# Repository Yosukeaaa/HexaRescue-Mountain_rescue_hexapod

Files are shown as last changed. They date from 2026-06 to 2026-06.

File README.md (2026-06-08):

HexaRescue is a mountain‑rescue hexapod robot designed to navigate rough terrain, detect potential victims, and transmit reliable information to rescue teams.
The robot combines robust mechanical design, modular electronics, and onboard AI to operate in challenging environments.



## Mechanical Design
HexaRescue is a 50 cm hexapod with six legs, each offering three degrees of freedom for stability and obstacle‑crossing.



The robot is built on three stacked layers:

  - Top layer — Jetson Nano + ESP32

  - Middle layer — 2S Li‑Po battery (centered for stability)

  - Bottom layer — SSC‑32U servo controller + power converters

Most parts are 3D‑printed in PETG, while the chassis is metal for rigidity.
The feet use TPE pads for improved grip on uneven terrain.

## Electrical Architecture
Power comes from a 2S Li‑Po battery, split into three rails:

  - Direct Li‑Po → SSC‑32U powering 20 servos
  - 5 V buck converter → Jetson Nano + ESP32
  - 3.3 V buck converter → sensors

## Sensor Placement
Sensors are positioned to maximize reliability:

  - GPS at the front, away from EMI sources
  - RGB + thermal cameras on a 2‑DOF camera arm
  - Distance sensor at the bottom for ground‑level obstacle detection

## Software Architecture & AI
The system uses a simple but effective communication scheme:

The ESP32 hosts a Wi‑Fi network and serves a web interface
The smartphone connects simultaneously to:

  - ESP32 → commands + telemetry
  - Jetson Nano → video stream



The Jetson Nano runs YOLOv5 to detect people.

When a detection occurs, the ESP32 cross‑checks it with thermal data from the GridEYE sensor. 

 

If both confirm a human presence, the operator receives an alert popup with timestamp and GPS coordinates.

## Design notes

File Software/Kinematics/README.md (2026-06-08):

## Inverse Kinematics
The inverse kinematics is a crucial part of any hexapod robot, as it determines how each leg should move to achieve a desired body position or trajectory.
For HexaRescue, the kinematic equations were developed at the beginning of the project using the 3D models of the robot to accurately define joint geometry and movement constraints.

These calculations were then validated in real conditions through the test scripts available in this folder.
They serve as the mathematical foundation for the robot’s locomotion, ensuring stable, precise and predictable movements across uneven terrain.



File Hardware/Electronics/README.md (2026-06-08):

HexaRescue is powered by a 2S Li‑Po battery. From this battery, three separate power rails are derived:

    - Servo power rail — The SSC‑32U board is connected directly to the Li‑Po and supplies power to the 20 servomotors 
    (18 for the legs, 2 for the camera arm).

    - 5V rail — A 5V buck converter steps down the battery voltage to power the Jetson Nano and the ESP32.

    - 3.3V rail — A 3.3V buck converter provides a stable voltage for all sensors.

A main power switch is placed right after the battery to ensure safety during startup and maintenance.

The following diagram shows the overall electrical architecture of the robot.



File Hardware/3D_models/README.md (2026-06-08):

This folder contains the 3D model files for HexaRescue.

HexaRescue

https://github.com/user-attachments/assets/52c7025c-e5b4-4ebd-b071-2c9e1bfe73b1

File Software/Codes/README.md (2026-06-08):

This folder contains all HexaRescue source code, except the Jetson Nano and the AI code.

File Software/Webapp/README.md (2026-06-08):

# Web Application Overview
The HexaRescue web application is divided into four main sections, each designed to give the operator a clear and efficient control interface.

  ## Status & Telemetry Panel
  This section displays the robot’s real‑time state through colored indicators.
  Each LED‑style indicator reflects the health of a subsystem (robot status, sensors, communication, ...).
  The panel also shows the robot’s live position by GPS coordinates.

  ## Multi‑View Camera Interface
  The operator can switch between three different video feeds:
  - RGB view — standard camera feed  
  - Thermal view — temperature‑based visualization  
  - Fusion view — combined RGB + thermal overlay for enhanced detection

 -->  --> 

  This setup provides a complete understanding of the environment, even in low‑visibility conditions.

  ## Robot Control Panel
  This section provides direct control over the robot’s movements:
  - Forward / backward  
  - Rotation  
  - Head movement (left/right and up/down)  

 In addition to directional controls, the interface includes sliders that allow the operator to adjust
  the robot’s walking height, body elevation, and overall movement speed, offering precise control
  over its locomotion.
  
  Commands are sent instantly through the ESP32, ensuring responsive control during navigation.

  ## Detection Alerts & History
  All confirmed detections appear in a dedicated alert feed.
  Each entry includes:
  - Detection time  
  - GPS coordinates  
  - Thermal signature  

  This creates a detailed history of all potential victims detected during the mission.

  ## Entire web application :


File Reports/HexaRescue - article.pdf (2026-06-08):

Abstract — This article presents the early development of HexaRescue, a hexapod [1] mountain rescue robot. The project focuses on creating a 3-DOF [2] leg architecture actuated by servomotors. Each prototype was individually tested. At this stage, three legs have been assembled and were set in motion. These early results confirm the feasibility of this hexapod but also the reliability of the chosen design.

Index terms — Hexapod, legged robot, Arduino, servomotor, inverse kinematics

I. INTRODUCTION

Hexapod robots offer advantages compared to wheeled robots. They can handle obstacles better and have greater stability on uneven terrain. HexaRescue is based on this idea. It is a 6-legged robot designed to assist rescue teams and reduce intervention time. Each leg has 3 degree of freedom (DOF). They are controlled by an SSC-32 board [3] and Arduino UNO [4]. The main structure is in metal, and the legs are 3D-printed in Polyethylene Terephthalate Glycol (PETG). The main goals of HexaRescue are to move on irregular terrain, detect victims using a thermal camera, and transmit their GPS position to rescue teams.

This article is organized as follows. Section II presents the mechanical design of the robot. Section III describes the electronic architecture and the components used. Section IV introduces the control code and the first locomotion tests. Finally, Section V presents the conclusions.

II. MECHANICAL DESIGN

The first version of the robot was made entirely in metal. It was a kit with servomotors and metal legs. However, this first version had several limitations. Firstly, the legs were too short so the robot would have difficulties straddling branches or rocks. Secondly, the build quality was insufficient. So, it was decided to keep only the metal body and 3D print the legs. This compromise gives HexaRescue good structural strength but also a strong and durable base for mounting the new legs.
The new legs were entirely designed using Computer-Aided Design (CAD) (Fig.1) with fusion360 [5]. Multiple versions were needed to obtain a leg that was rigid, practical, and aesthetically clean. Then, these legs were manufactured using a 3D printer and Computer-Aided Manufacturing (CAM). PETG is the filament used because it has good mechanical properties: lightweight, mechanical strength, and good shock resistance. Moreover, using CAD/CAM [6] and 3D printed legs is good for adjusting the model and allows modular parts that can easily be replaced.

*E-mail : pierre.masseglia@etu.unice.fr

Finally, a 3 DOF leg architecture was chosen for the legs because, compared to a 2 DOF leg architecture, it offers a wider range of motion. Thanks to a 3 DOF leg architecture, a leg can step over an obstacle by lifting its hip and rotating the leg. Some motions would not be possible without the 3rd DOF.

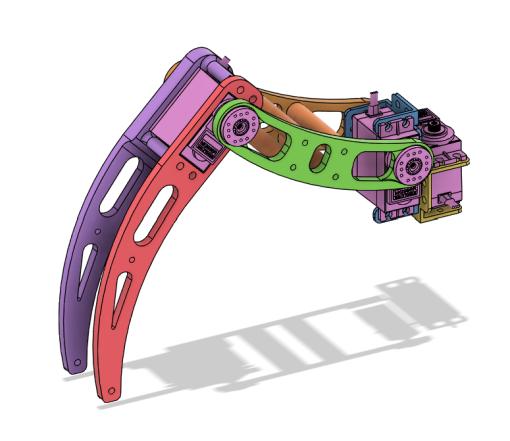
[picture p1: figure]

Figure 1 : CAD model of a single 3-DOF leg created in Fusion 360.

III. ELECTRONIC ARCHITECTURE

The electronic architecture of HexaRescue is composed of boards and sensors, as illustrated in Fig. 2.

A. Main electronics
The electronic architecture of HexaRescue is based on an Arduino UNO combined with an SSC-32 board, used because it can pilot several servomotors at the same time. This board is precise and reliable. The legs use servomotors TD-8135MG [7] with a force of 35 kg.cm. It offers high torque which is necessary to hold the weight of the robot, to facilitate motions, but also to carry some light tools. HexaRescue is now powered by a laboratory power supply, so it currently operates exclusively via wired power.
B. Sensors
The robot also integrates several sensors designed to improve its perception of the environment. A HC SR-04 [8], an ultrasonic sensor, is placed at the front of the body to detect obstacles and avoid front collisions. A thermal camera AMG8833 [9] is also fixed at the front of the robot. It can distinguish heat sources and is a key element for detecting victims in mountain environments. This combination of sensors provides an initial perception layer, which will be expanded as the prototype continues to develop.

## HexaRescue – Hexapod mountain rescue robot

Masseglia Pierre

University of Côte d'Azur, Polytech ‘Lab UPR UniCca 7498, Sophia Antipolis, France

Finally, HexaRescue uses an HC-05 [10] Bluetooth module to be controlled by an application on a smartphone.

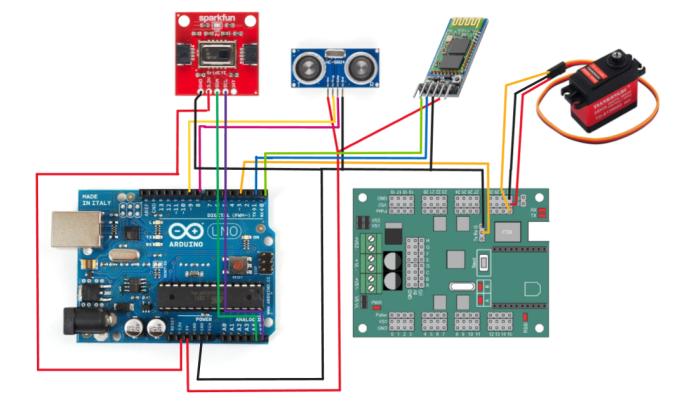
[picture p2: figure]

Figure 2 : Electronic achitecture of HexaRescue.

IV. LOCOMOTION AND CODE

A. Inverse kinematics and control of the legs
The locomotion of HexaRescue is based on the calculations of inverse kinematics equations [11]. This method allows converting a target position in space (x, y, z) into the corresponding angles for each servomotor (θ1, θ2, θ3), where θ₁, θ₂, and θ₃ represent the hip yaw, hip pitch, and knee pitch angles respectively.
These calculations are the basis of every leg movement and that ensures that each foot follows the good trajectory with precision.
B. Locomotion modes and tripod gait
HexaRescue integrates different operational modes for the moment.
- Shut down mode: the robot is inactive. All the legs are pointing toward the sky, and the body is resting on the ground, as presented in fig.3.
- Enable mode: the legs move from their shut down position to the neutral position, and they slowly lift the robot into a stable posture, as presented in fig.4.
- Neutral position mode: each leg is in a stable position without any movement.
- Forward mode: the robot walks using a tripod gait, a gait in which three legs are moving while the others are stabilizing the robot, as shown in Table I.

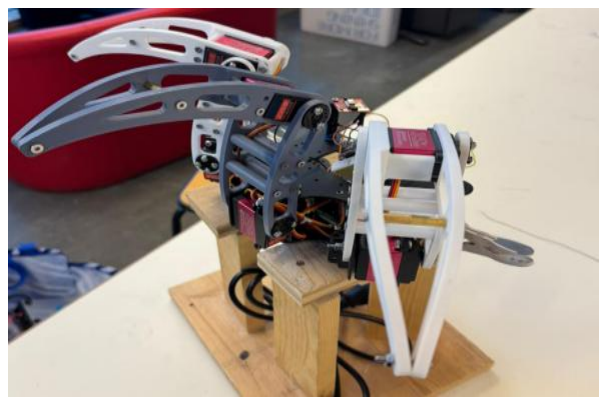
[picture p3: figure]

Figure 3 : Shut down mode.

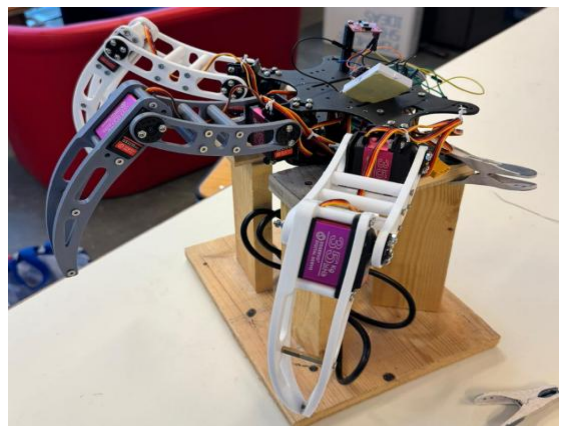
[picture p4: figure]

Figure 4 : Enable mode.

TABLE I. Table representing the tripod gait, with black cells indicating when the legs are in contact with the ground.

LEG 1

LEG 2

LEG 3

LEG 4

LEG 5

LEG 6

The height of the robot can also be adjusted dynamically. This allows the body of the robot to be raised or lowered depending on the user’s need or the terrain.

C. Code structure
All the elements described above were integrated into the main program of HexaRescue. To improve accessibility and maintenance, the code was placed into different classes and files.
Each class has a precise role: one manages the legs, another handles the inverse kinematics calculations, and another communicates with the SSC-32 board to send all the data at the same time to the servomotors.
This organization helps keep the code readable and structured, and makes it easier to improve, such as new functions or sensors. All this code was written in the Arduino IDE [12].
V. CONCLUSION
HexaRescue is a hexapod robot designed to move in a stable way thanks to the inverse kinematics equations and the tripod gait which is simple but effective. At this stage, three legs have been assembled and tested but all the different functioning modes were correctly integrated and tested, as well as the sensors. The structure of the code is helpful to maintain the robot and to add new gaits or sensors.

It can be a lot more evolutive than before. This works is a solid base for HexaRescue, and to add new functionalities. REFERENCES

[1] S. Hirose and Y. Umetani, “Kinematic control of a six -legged walking
vehicle,” Proceedings of the 5th International Symposium on Industrial Robots, pp. 245
–254, 1976.
[2] J.
-L. Lagrange, Mécanique Analytique. Paris, France: Desaint, 1788.
[3] Lynxmotion, SSC-32 Servo Controller User Guide, Lynxmotion/RobotShop, 2005
[4] Arduino, Arduino UNO Rev3 Datasheet, Arduino AG, 2015.
[5] Autodesk, Fusion 360 Official Documentation, Autodesk Inc., 2013.
[6] D. T. Ross, “Computer
-Aided Design: A Statement of Objectives,” Proceedings of the Eastern Joint Computer Conference, pp. 313 –319,
1960.
[7] Wishiot, TD
-8135MG High

-Torque Servo Motor Specifications, Wishiot, 2020.
[8] SparkFun Electronics, HC-SR04 Ultrasonic Distance Sensor Datasheet, SparkFun, 2014.
[9] Panasonic Corporation, AMG8833 Infrared Array Sensor “Grid -EYE”
Datasheet, Panasonic, 2016.
[10]
Y

-MCU, HC-05 Bluetooth Module Datasheet, JY

-MCU / Huayuxing
Electronics, 2010.
[11] D. L. Pieper, “The kinematics of manipulators under computer control,” Ph.D. dissertation, Dept. Mech. Eng., MIT, Cambridge, MA, 1969.
[12] Arduino, Arduino IDE
– Integrated Development Environment Documentation, Arduino AG, 2015.

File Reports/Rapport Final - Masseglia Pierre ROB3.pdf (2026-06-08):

### Robotique, Systèmes autonomes

# Projet de robotique – Rapport Final

## Année scolaire 2025-2026

## HexaRescue – Hexapode de secours en montagne

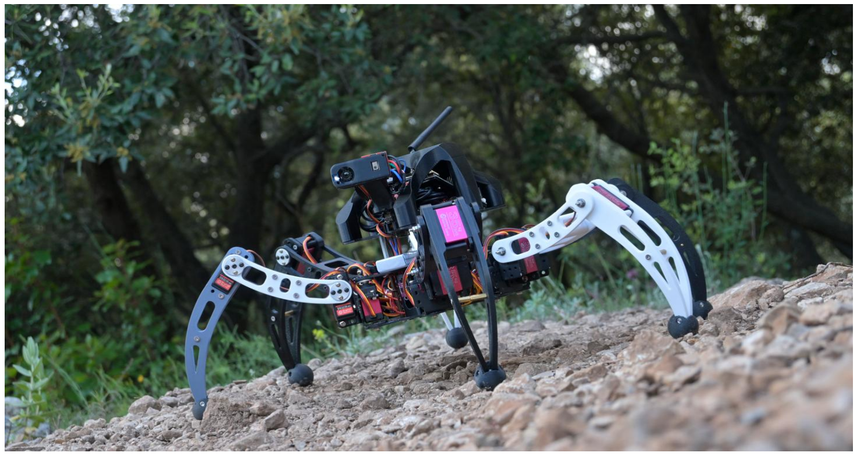
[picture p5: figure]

# Etudiant : Masseglia Pierre

Ecole Polytechnique Universitaire de Nice Sophia-Antipolis, formation robotique (systèmes autonomes) 930 route des Colles, 06410 BIOT

SOMMAIRE

I.1. Caractéristiques mécaniques

I.2. Matériaux utilisés

II.1. Schéma électrique

II.2. Implantation des capteurs

III.1. Système de contrôle du robot

III.2. Intelligence artificielle

IV.1. Coût du projet

IV.2. Difficultés rencontrées

IV.3. Améliorations possibles du rapport bibliographique

# Introduction

Chaque année en France, plusieurs centaines d’interventions sont réalisées en montagne pour porter secours à des victimes, parfois dans des zones difficiles d’accès. Ces conditions rallongent les délais d’intervention et peuvent réduire les chances de survie. Un outil capable d’explorer rapidement un terrain accidenté et de transmettre des informations fiables constitue donc une aide précieuse pour les équipes de secours.

Le robot HexaRescue répond à cet objectif. Il s’agit d’un hexapode d’environ 50 cm, capable d’évoluer sur des terrains complexes grâce à ses six pattes. Équipé de capteurs, il peut détecter et éviter les obstacles, repérer la présence potentielle de victimes et transmettre leur position GPS.

Le présent rapport expose l’ensemble des démarches de conception du prototype.

# Chapitre I : Conception mécanique

I.1. Caractéristiques mécaniques

HexaRescue est un robot hexapode conçu pour évoluer dans des environnements montagneux difficiles d’accès. Sa structure mécanique repose sur une architecture à six pattes, chacune dotée de trois degrés de liberté, offrant une excellente stabilité et une capacité de franchissement élevée. Cette configuration permet au robot de progresser sur des terrains irréguliers, de franchir des obstacles et de maintenir une posture stable même en conditions dégradées.

La structure générale du robot est organisée en trois étages distincts, chacun dédié à un sous-système spécifique :

- L’étage supérieur accueille l’électronique principale, notamment la Jetson Nano et l’ESP32. Cette position facilite l’accès, la maintenance et limite l’exposition aux chocs.
- L’étage intermédiaire intègre la batterie LiPo 2S. Placée au centre du robot, elle abaisse le centre de gravité et améliore la stabilité lors de la marche.
- L’étage inférieur supporte la carte SSC32U et les différents convertisseurs d’alimentation. Cette disposition réduit l’encombrement des câbles et simplifie le câblage des servomoteurs.

Le robot embarque également un bras caméra orientable à deux degrés de liberté (yaw et tilt), permettant de diriger précisément les caméras vers une zone d’intérêt.

I.2. Matériaux utilisés

Le choix des matériaux a été guidé par la nécessité d’obtenir un robot robuste, léger et résistant aux contraintes mécaniques rencontrées en montagne.

- Le châssis est réalisé en métal afin d’assurer une rigidité élevée et de limiter les déformations lors des déplacements ou des chocs.
- Tous les autres éléments ont été imprimés en 3D en PETG avec plusieurs périmètres et un remplissage de type gyroid. Ce choix offre un compromis optimal entre résistance, flexibilité et temps d’impression.
- Les extrémités des pattes possèdent des boudins en TPE, plus souples que le TPU classique, qui améliorent l’adhérence au sol et absorbent mieux les irrégularités du terrain.

# Chapitre II : Conception électrique

II.1. Schéma électrique

L’alimentation du robot repose sur une batterie LiPo 2S. À partir de cette batterie, trois étages d’alimentation distinctes sont dérivés :

- La carte SSC32U [1] est alimentée directement en sortie de la LiPo. Cette carte alimente les 20 servomoteurs du robot (18 pour les pattes, 2 pour le bras caméra).
- Un buck 5V convertit la tension de la batterie vers 5 V, tension utilisée pour alimenter la Jetson Nano et l’ESP32 [2].
- Un buck 3,3V est lui dédié aux capteurs afin d’assurer une alimentation stable et suffisante à l’ensemble des capteurs.

Un interrupteur général est placé juste après la batterie pour garantir la sécurité lors de l’allumage et de la maintenance.

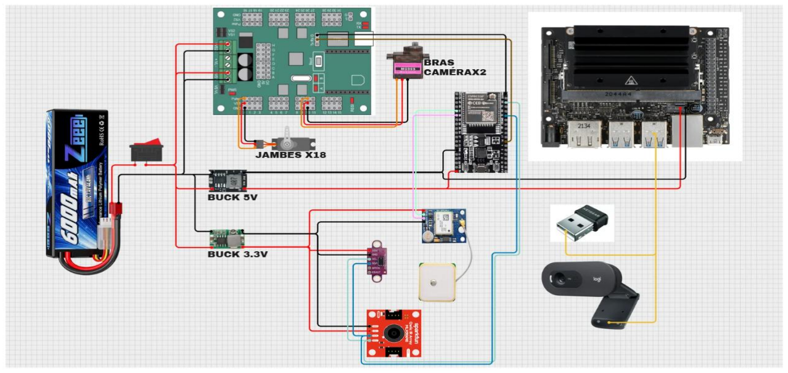
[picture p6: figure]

Figure II.1. Schéma électrique d’HexaRescue

II.2. Implantation des capteurs

Les capteurs ont été positionnés de manière stratégique pour optimiser la qualité des mesures et réduire les interférences :

- Le capteur GPS est placé à l’avant du robot, éloigné de la Jetson Nano et de l’ESP32 pour limiter les perturbations électromagnétiques et fiabiliser les données reçues.
- Les caméras (RGB et thermique) sont montées sur le bras orientable, permettant de balayer la scène et de cibler précisément une zone d’intérêt.
- Le capteur de distance est situé à l’étage le plus bas du châssis pour détecter les obstacles proches du sol.

Cette disposition assure une acquisition de données fiable et cohérente avec les besoins du robot.

# Chapitre III : Architecture logicielle et intelligence embarquée

III.1. Système de contrôle du robot

Le fonctionnement logiciel repose sur une communication simple entre l’ESP32, la Jetson Nano et un smartphone.

L’ESP32 génère son propre réseau Wifi auquel l’opérateur se connecte depuis son smartphone. En entrant l’adresse IP de l’ESP32 dans un navigateur, l’utilisateur accède à une application web embarquée, stockée dans l’ESP32.

Une fois la webapp chargée, le smartphone établit deux connexions simultanées :

- Une vers l’ESP32 pour les commandes et la télémétrie.
- Une vers la Jetson Nano pour le flux vidéo.

III.2. Intelligence Artificielle

La Jetson Nano exécute un modèle de détection basé sur YOLOv5 [3], entraîné pour identifier des personnes dans l’environnement. Lorsqu’une détection est réalisée, la Jetson envoie une alerte à l’ESP32 via le module WebSocket.

L’ESP32 croise alors cette information avec les données de la caméra thermique GridEYE. Si les deux capteurs confirment la présence d’une personne, un popup d’alerte apparaît dans la webapp, contenant l’heure de détection ainsi que les coordonnées GPS de la victime. Cette fusion de capteurs permet de réduire les faux positifs et d’améliorer la fiabilité du système.

Voici l’algorithme de fonctionnement de la détection d’une victime.

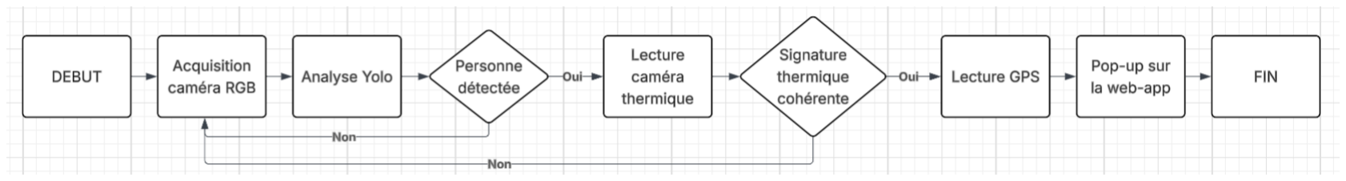
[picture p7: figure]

Figure III.1. Algorithme de détection et confirmation multi-capteurs

# Chapitre IV : Analyse des coûts et retour d’expérience

IV.1. Coût du projet

Le coût total du projet HexaRescue peut être estimé en prenant en compte le matériel utilisé ainsi que le temps de travail nécessaire à la conception.

Concernant le coût matériel, en comptant les différentes cartes électroniques, les servomoteurs, et tous les capteurs utilisés, nous en avons pour environ 600€.

Concernant le coût ingénieur, nous avons passé environ 24*4h = 96h en cours de robotique expérimentale. Personnellement, je pense avoir travaillé 30*5h = 150h en plus, soit un total de 246h.

Au taux horaire, cela représente un total de 246 * 23,75€ = 5 842,5€

Ainsi, au total, HexaRescue aura coûté 6 442,5€.

IV.2. Difficultés rencontrées

La réalisation du robot a été marquée par plusieurs difficultés techniques importantes.

La première série de problèmes est apparue lors des premiers tests de marche. La carte SSC-32U, utilisée pour piloter les servomoteurs, causait parfois des comportements inattendus et imprévisibles. Les pattes du robot entraient donc régulièrement en collision, ce qui nécessitait de recalibrer entièrement les pattes à chaque essai. Cette phase a été particulièrement chronophage, car le moindre décalage sur un seul servomoteur entraînait le démontage de la patte entière afin de la recalibrer.

Une autre difficulté majeure a concerné la Jetson Nano. Sa première mise en fonctionnement s’est avérée délicate : installation du système, drivers, dépendances IA, compatibilité des versions Python, gestion des caméras, et stabilité générale. Même une fois fonctionnelle, la carte restait difficile à utiliser de manière fiable, ce qui a fortement ralenti le développement de la partie vision et détection.

Ces obstacles ont représenté une part significative du temps de développement, mais ils ont également permis d’acquérir une meilleure maîtrise des compétences nécessaires pour intégrer des cartes embarquées, ainsi que de l’intelligence artificielle.

IV.3. Améliorations possibles du rapport bibliographique

Au début du projet, le rapport bibliographique n’intégrait pas la partie concernant l’intelligence artificielle ni l’utilisation de la Jetson Nano. Ces éléments avaient été laissés de côté, car ils ne semblaient pas prioritaires dans la phase initiale. Cependant, au cours de la réalisation, de nombreux problèmes techniques liés à cette carte sont apparus. Ces imprévus ont conduit à consacrer beaucoup plus de temps que prévu à la Jetson Nano. Ainsi, une amélioration majeure pour un futur projet similaire serait d’anticiper davantage la complexité de l’intégration de l’IA, en prévoyant dès le départ un temps dédié à la configuration, aux tests et à la stabilisation de la plateforme de calcul embarquée.

# Conclusion et perspectives

Au terme de cette année de développement, nous avons réussi à concevoir un robot de secours capable de se déplacer sur terrains accidentés et d’utiliser ses caméras, associées à l’IA, pour détecter des personnes. Ce prototype valide les choix techniques réalisés et montre le potentiel d’un robot d’assistance en milieu difficile.

Plusieurs améliorations sont toutefois envisageables. L’ajout d’un accéléromètre permettrait au robot de conserver une position stable. Le développement de nouvelles démarches et le renforcement de la structure amélioreraient la fiabilité globale.
À plus long terme, l’objectif serait de rendre le robot autonome, capable de scanner son environnement et de naviguer sans intervention humaine.

Enfin, il serait pertinent d’utiliser un second protocole longue portée (LoRa, radio, LTE) en complément du Wi-Fi : le robot conserverait le Wi-Fi pour les communications à courte distance, tandis qu’un lien LoRa ou radio assurerait une transmission fiable sur de longues distances, les deux fonctionnant en parallèle.

Ces perspectives ouvrent la voie à une version plus robuste, plus autonome et mieux adaptée aux conditions réelles d’intervention.

# Références

[1] Guide utilisateur Lynxmotion SSC-32U (PDF) : lynxmotion_ssc-32u_usb_user_guide.pdf (https://wiki.lynxmotion.com/info/wiki/lynxmotion/download/servo-erector-set-system/ses-electronics/ses-modules/ssc-32u/WebHome/lynxmotion_ssc-32u_usb_user_gui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)
[2] Upesy : Pinout complet ESP32 : https://www.upesy.fr/blogs/tutorials/esp32-pinout-reference-gpio-pins-ultimate-guide (https://www.upesy.fr/blogs/tutorials/esp32-pinout-reference-gpio-pins-ultimate-guide)
[3] Ultralytics : Documentation YOLOv5 : Ultralytics YOLOv5 | Ultralytics Docs (https://docs.ultralytics.com/models/yolov5)

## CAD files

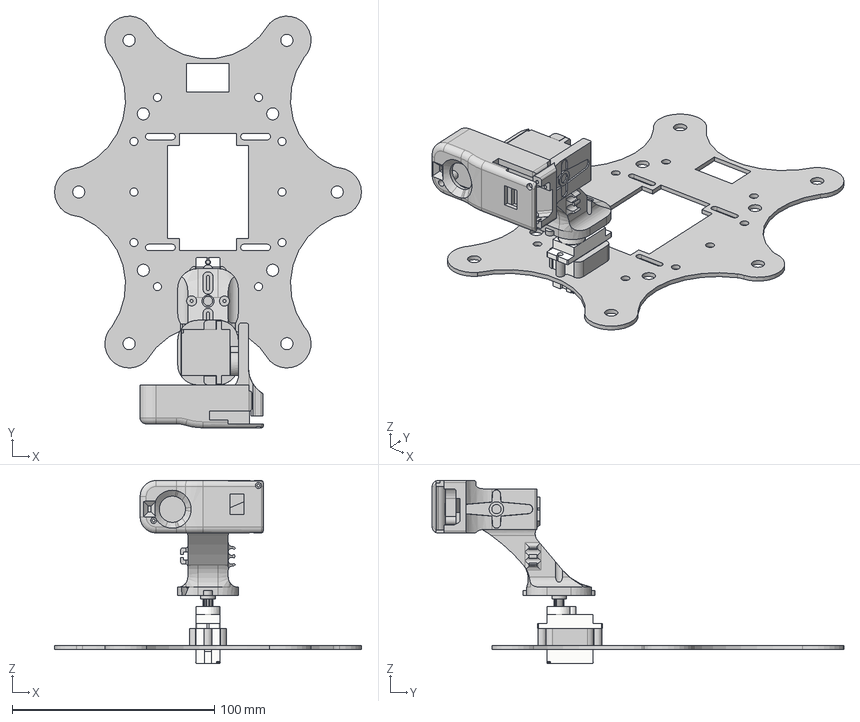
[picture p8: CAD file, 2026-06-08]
Hardware/3D_models/Camera Arm.step
151.8 x 203.6 x 90.5 mm

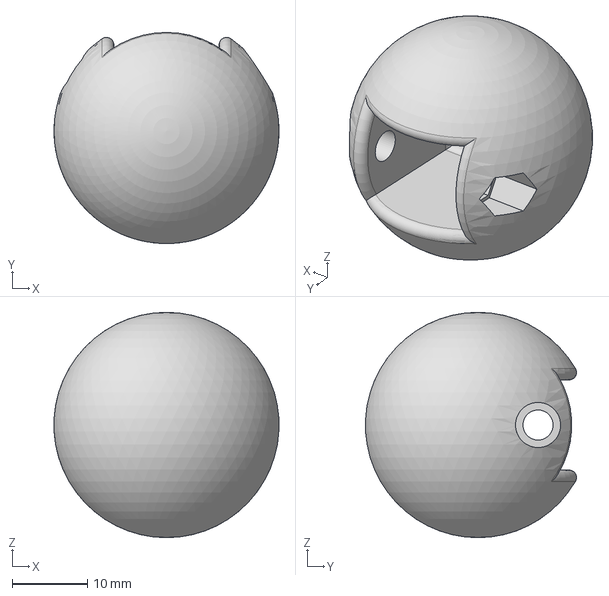
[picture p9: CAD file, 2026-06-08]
Hardware/3D_models/Embouts pattes.step
29.9 x 28.1 x 30.0 mm

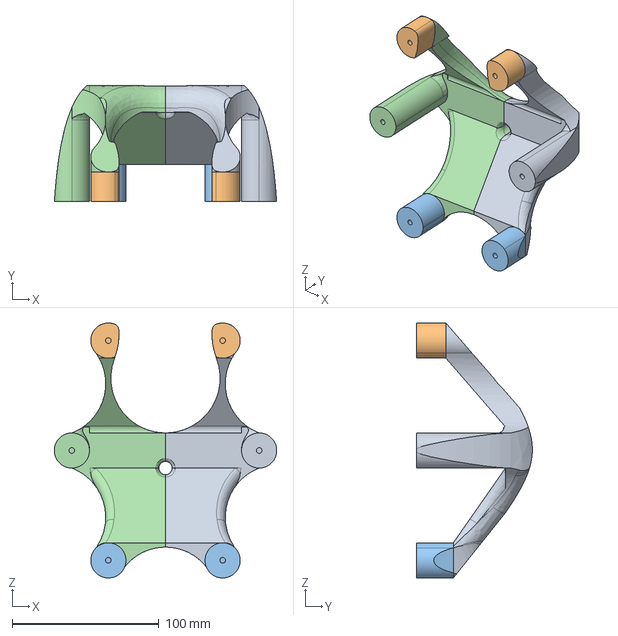
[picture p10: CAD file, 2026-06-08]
Hardware/3D_models/Dome V2.step
151.7 x 79.0 x 174.0 mm

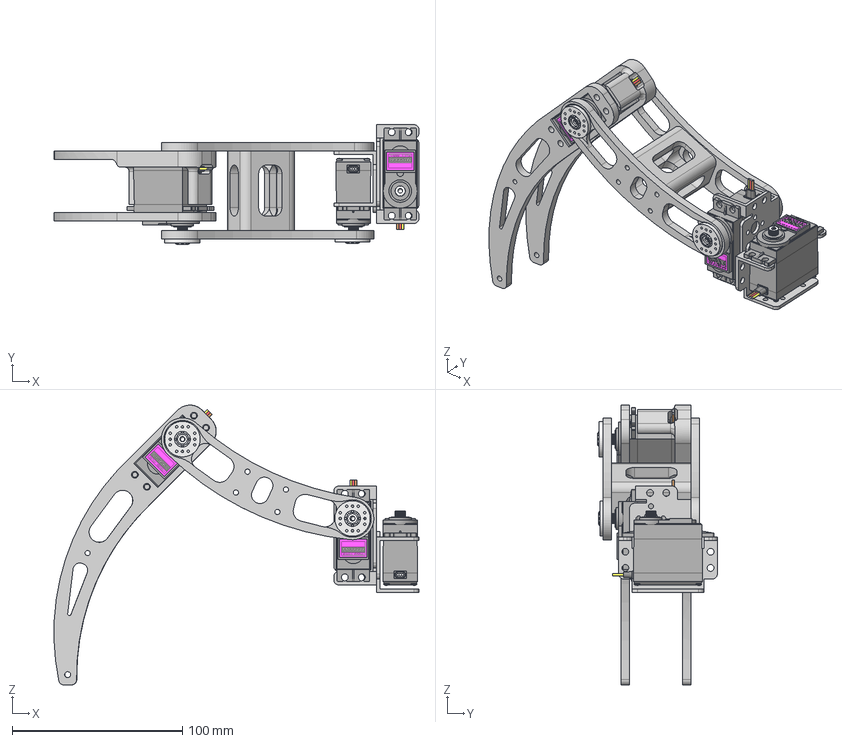
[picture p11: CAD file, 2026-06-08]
Hardware/3D_models/LegV5.step
214.1 x 70.3 x 164.1 mm

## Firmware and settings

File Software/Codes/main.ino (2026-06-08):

#include "Leg.h"
#include "inverseKine.h"
#include "Gaits.h"
#include "SSC32.h"
#include "webapp.h"

#include <WiFi.h>
#include <WebServer.h>
#include <WebSocketsServer.h>
#include <ArduinoJson.h>
#include <TinyGPSPlus.h>
#include "esp_wifi.h"

const char* AP_SSID = "HexaRescue";
const char* AP_PASSWORD = "hexapode42";

WebServer httpServer(80);
WebSocketsServer wsServer(81);

TinyGPSPlus gps;
HardwareSerial GPSserial(1);

float gpsLat = 0.0;
float gpsLng = 0.0;
float gpsAlt = 0.0;
bool gpsValid = false;

const int PINS[18] = {
  31, 30, 29,
  12, 13, 14,
  27, 26, 25,
  5, 6, 7,
  19, 18, 17,
  1, 2, 3
};

#define CAM_YAW_PIN 10
#define CAM_PITCH_PIN 11

Leg HexaRescue[6] = {
  Leg(1, -60.0, 0.0, PINS[0], PINS[1], PINS[2]),
  Leg(2, 55.0, 0.0, PINS[3], PINS[4], PINS[5]),
  Leg(3, 0.0, 0.0, PINS[6], PINS[7], PINS[8]),
  Leg(4, 0.0, 0.0, PINS[9], PINS[10], PINS[11]),
  Leg(5, 55.0, 0.0, PINS[12], PINS[13], PINS[14]),
  Leg(6, -60.0, 0.0, PINS[15], PINS[16], PINS[17])
};

Gaits gait;
SSC32 ssc(Serial2, PINS, 18);

char command = '\0';
bool robotEnabled = false;
bool robotNeutral = false;
bool distanceLock = false;
float groundHeight = -120.0;
float stepHeight = 80.0;
int velocity = 1500;

int camYawUs = 1500;
int camPitchUs = 1500;
bool camDirty = false;
bool camCenter = false;

void sendCameraServos() {
  if (!camDirty) return;
  int transition = camCenter ? 500 : 80;
  char cmd[64];
  snprintf(cmd, sizeof(cmd), "#%dP%d#%dP%dT%d\r",
           CAM_YAW_PIN, camYawUs, CAM_PITCH_PIN, camPitchUs, transition);
  if (SSC32::serial2Mutex && xSemaphoreTake(SSC32::serial2Mutex, pdMS_TO_TICKS(5)) == pdTRUE) {
    Serial2.print(cmd);
    xSemaphoreGive(SSC32::serial2Mutex);
    camDirty = false;
    camCenter = false;
  }
}

void centerCamera() {
  camYawUs = 1500;
  camPitchUs = 1500;
  camDirty = true;
}

#include <Wire.h>
#include <VL53L0X.h>
#include <SparkFun_GridEYE_Arduino_Library.h>

VL53L0X sensor;
GridEYE grideye;

volatile int distanceVL53 = -1;
volatile bool bodyDetected = false;
volatile bool yoloDetected = false;
const float THERMAL_DIFF_THRESHOLD = 2.5;  // °C de différence min pour confirmer

float lastTempMax = 0.0;
float lastTempAvg = 0.0;
float lastTempMin = 0.0;
bool gridEyeOK = false;
float lastGrid[64] = { 0 };

unsigned long lastTelemSend = 0;

void sendTelemetry() {
  if (millis() - lastTelemSend < 1000) return;
  lastTelemSend = millis();

  bool tempValid = gridEyeOK && (lastTempMax > -40.0) && (lastTempMax < 150.0);

  StaticJsonDocument<2048> doc;
  doc["type"] = "telem";
  doc["distance"] = distanceVL53;
  doc["tempMax"] = tempValid ? lastTempMax : 0.0;
  doc["tempAvg"] = tempValid ? lastTempAvg : 0.0;
  doc["tempValid"] = tempValid;
  doc["bodyDetected"] = bodyDetected;
  doc["yoloDetected"] = yoloDetected;
  doc["robotEnabled"] = robotEnabled;
  doc["robotNeutral"] = robotNeutral;
  doc["distanceLock"] = distanceLock;
  doc["gpsValid"] = gpsValid;
  doc["gpsLat"] = gpsLat;
  doc["gpsLng"] = gpsLng;
  doc["gpsAlt"] = gpsAlt;
  JsonArray grid = doc.createNestedArray("grid");
  for (int i = 0; i < 64; i++) grid.add(lastGrid[i]);

  char buf[2048];
  serializeJson(doc, buf);
  wsServer.broadcastTXT(buf);
}

enum EmoteType { EMOTE_NONE,
                 EMOTE_HELLO,
                 EMOTE_TWIST,
                 EMOTE_JUMP };
EmoteType currentEmote = EMOTE_NONE;

void webSocketEvent(uint8_t num, WStype_t type, uint8_t* payload, size_t length) {
  if (type != WStype_TEXT) return;

  StaticJsonDocument<256> doc;
  if (deserializeJson(doc, payload)) return;

  const char* msgType = doc["type"] | "";

  if (strcmp(msgType, "ping") == 0) {
    wsServer.sendTXT(num, "{\"type\":\"pong\"}");
    return;
  }
  if (strcmp(msgType, "cmd") == 0) {
    const char* c = doc["cmd"] | "S";
    command = c[0];
    return;
  }
  if (strcmp(msgType, "param") == 0) {
    const char* key = doc["key"] | "";
    int value = doc["value"] | 0;
    if (strcmp(key, "H") == 0) groundHeight = -(float)value;
    if (strcmp(key, "U") == 0) stepHeight = (float)value;
    if (strcmp(key, "V") == 0) velocity = value;
    return;
  }
  if (strcmp(msgType, "cam") == 0) {
    int yaw = doc["yaw"] | 1500;
    int pitch = doc["pitch"] | 1500;
    bool center = doc["center"] | false;
    camYawUs = constrain(yaw, 1000, 2000);
    camPitchUs = constrain(pitch, 1000, 2000);
    camDirty = true;
    camCenter = center;
    return;
  }
  if (strcmp(msgType, "emote") == 0) {
    const char* name = doc["name"] | "";
    if (strcmp(name, "hello") == 0) {
      command = 'E';
      currentEmote = EMOTE_HELLO;
    }
    if (strcmp(name, "twist") == 0) {
      command = 'E';
      currentEmote = EMOTE_TWIST;
    }
    if (strcmp(name, "jump") == 0) {
      command = 'E';
      currentEmote = EMOTE_JUMP;
    }
    return;
  }
  if (strcmp(msgType, "yolo") == 0) {
    bool yoloSaw = doc["yoloDetected"] | false;
    if (yoloSaw) {
      // Confirmation thermique obligatoire
      bool thermalConfirmed = gridEyeOK && (lastTempMax > -40.0) && (lastTempMax - lastTempMin >= THERMAL_DIFF_THRESHOLD);
      yoloDetected = thermalConfirmed;
      Serial.printf("[YOLO] Detection YOLO=%s | TempMax=%.1f TempAvg=%.1f | Thermal=%s\n",
                    yoloSaw ? "OUI" : "NON",
                    lastTempMax, lastTempAvg,
                    thermalConfirmed ? "CONFIRMEE" : "NON CONFIRMEE");
    } else {
      yoloDetected = false;
    }
    return;
  }
}

void networkTask(void* pvParameters) {
  while (true) {
    httpServer.handleClient();
    wsServer.loop();
    sendTelemetry();
    sendCameraServos();
    vTaskDelay(1);
  }
}

void captorsTask(void* pvParameters) {
  unsigned long lastVL53 = 0;
  unsigned long lastGridEye = 0;

  while (true) {
    // GPS
    while (GPSserial.available()) {
      gps.encode(GPSserial.read());
      if (gps.location.isUpdated()) {
        gpsLat = gps.location.lat();
        gpsLng = gps.location.lng();
        gpsAlt = gps.altitude.meters();
        gpsValid = true;
      }
    }

    unsigned long now = millis();

    // VL53L0X
    if (now - lastVL53 >= 50) {
      lastVL53 = now;
      int d = sensor.readRangeContinuousMillimeters();
      if (!sensor.timeoutOccurred()) distanceVL53 = d;
      else distanceVL53 = -1;
    }

    // GridEYE
    if (now - lastGridEye >= 300) {
      lastGridEye = now;
      if (gridEyeOK) {
        float validPixels[64];
        int validCount = 0;
        bool readOK = true;

        for (int i = 0; i < 64; i++) {
          float t = grideye.getPixelTemperature(i);
          if (t < 0.0 || t > 80.0) continue;  // filtre bruit
          lastGrid[i] = t;
          validPixels[validCount++] = t;
        }

        if (validCount < 32) {  // moins de la moitié valide = lecture suspecte
          readOK = false;
        }

        if (readOK) {
          // Tri pour médiane
          for (int i = 0; i < validCount - 1; i++)
            for (int j = i + 1; j < validCount; j++)
              if (validPixels[j] < validPixels[i]) {
                float tmp = validPixels[i];
                validPixels[i] = validPixels[j];
                validPixels[j] = tmp;
              }

          float median = (validCount % 2 == 0)
                           ? (validPixels[validCount / 2 - 1] + validPixels[validCount / 2]) / 2.0
                           : validPixels[validCount / 2];

          float biggest = validPixels[validCount - 1];
          float smallest = validPixels[0];
          float sumTemp = 0;
          for (int i = 0; i < validCount; i++) sumTemp += validPixels[i];

          lastTempMax = biggest;
          lastTempAvg = sumTemp / validCount;
          lastTempMin = smallest;

          // Détection : au moins 1 pixel dépasse médiane + seuil
          const float MEDIAN_THRESHOLD = 3.0;
          bodyDetected = (biggest - median >= MEDIAN_THRESHOLD);

          Serial.printf("[THERMAL] median=%.1f max=%.1f diff=%.1f body=%s\n",
                        median, biggest, biggest - median, bodyDetected ? "OUI" : "NON");
        }
      }
    }

    vTaskDelay(1);
  }
}

void setup() {
  Serial.begin(115200);

  GPSserial.begin(9600, SERIAL_8N1, 34, -1);
  Serial2.begin(9600, SERIAL_8N1, 16, 17);
  ssc.begin(9600);

  Wire.begin(21, 22);

  sensor.setTimeout(500);
  if (!sensor.init()) Serial.println("[VL53L0X] FAIL");
  else {
    sensor.startContinuous(50);
    Serial.println("[VL53L0X] OK");
  }

  grideye.begin();
  delay(100);
  float testTemp = grideye.getPixelTemperature(0);
  gridEyeOK = (testTemp > -40.0 && testTemp < 150.0);
  Serial.println(gridEyeOK ? "[GridEYE] OK" : "[GridEYE] FAIL");

  SSC32::serial2Mutex = xSemaphoreCreateMutex();
  centerCamera();

  WiFi.softAP(AP_SSID, AP_PASSWORD);
  Serial.print("[WiFi] IP: ");
  Serial.println(WiFi.softAPIP());

  WiFi.softAP(AP_SSID, AP_PASSWORD, 6, 0, 4, false);

  httpServer.on("/", []() {
    httpServer.send_P(200, "text/html", INDEX_HTML);
  });
  httpServer.begin();
  Serial.println("[HTTP] pret");

  wsServer.begin();
  wsServer.onEvent(webSocketEvent);
  Serial.println("[WS] pret port 81");

  xTaskCreatePinnedToCore(networkTask, "networkTask", 12288, NULL, 2, NULL, 0);
  xTaskCreatePinnedToCore(captorsTask, "captorsTask", 8192, NULL, 1, NULL, 1);
}

void loop() {

  if (command == '\0') return;
  
  if (command == 'S') {
    if (robotEnabled) gait.shutDown(HexaRescue, ssc);
    robotEnabled = false;
    robotNeutral = false;
    return;
  }
  if (command == 'O') {
    if (!robotEnabled) gait.turnOn(HexaRescue, ssc);
    robotEnabled = true;
    robotNeutral = false;
    return;
  }

  if (!robotEnabled) return;

  switch (command) {
    case 'z': gait.tripodGaitForward(HexaRescue, ssc); break;
    case 'q': gait.tripodGaitLeftTurn(HexaRescue, ssc); break;
    case 's': gait.tripodGaitBackward(HexaRescue, ssc); break;
    case 'd': gait.tripodGaitRightTurn(HexaRescue, ssc); break;
    case 'N':
      gait.neutralPosition(HexaRescue, ssc);
      robotNeutral = true;
      distanceLock = false;
      break;
  }

  if (command == 'E' && robotEnabled) {
    switch (currentEmote) {
      case EMOTE_HELLO: gait.hello(HexaRescue, ssc); break;
      case EMOTE_TWIST: gait.twist(HexaRescue, ssc); break;
      case EMOTE_JUMP: gait.jump(HexaRescue, ssc); break;
      default: break;
    }
    currentEmote = EMOTE_NONE;
    command = 'N';
    return;
  }
}

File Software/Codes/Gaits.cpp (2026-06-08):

#include "Gaits.h"
#include "Leg.h"
#include "inverseKine.h"
#include "SSC32.h"

// Variables externes définies dans main
extern float groundHeight;
extern float stepHeight;
extern int velocity;
extern char command;  // mis à jour par WebSocket

int nbPts = 4;
float amplitude = 100.0;
int bodyDistance = 150;
int bodyDistanceCorners = 40;
float amplitude_turn = 50.0;

// Coordonnées pour le tripod gait forward
int coordinatestripodForwardFL[2] = { 175, 75 };
int coordinatestripodForwardFR[2] = { -175, -75 };
int coordinatestripodForwardML[2] = { 50, -50 };
int coordinatestripodForwardMR[2] = { -50, 50 };
int coordinatestripodForwardBL[2] = { -75, -175 };
int coordinatestripodForwardBR[2] = { 75, 175 };

// Coordonnées pour le tripod gait backward
int coordinatestripodBackwardFL[2] = { 75, 175 };
int coordinatestripodBackwardFR[2] = { -75, -175 };
int coordinatestripodBackwardML[2] = { -50, 50 };
int coordinatestripodBackwardMR[2] = { 50, -50 };
int coordinatestripodBackwardBL[2] = { -175, -75 };
int coordinatestripodBackwardBR[2] = { 175, 75 };

// Coordonnées pour le tripod gait left turn
int coordinatestripodLeftTurnFL[2] = { -35, 35 };
int coordinatestripodLeftTurnFR[2] = { -35, 35 };
int coordinatestripodLeftTurnML[2] = { -35, 35 };
int coordinatestripodLeftTurnMR[2] = { -35, 35 };
int coordinatestripodLeftTurnBL[2] = { -35, 35 };
int coordinatestripodLeftTurnBR[2] = { -35, 35 };

// Coordonnées pour le tripod gait right turn
int coordinatestripodRightTurnFL[2] = { 35, -35 };
int coordinatestripodRightTurnFR[2] = { 35, -35 };
int coordinatestripodRightTurnML[2] = { 35, -35 };
int coordinatestripodRightTurnMR[2] = { 35, -35 };
int coordinatestripodRightTurnBL[2] = { 35, -35 };
int coordinatestripodRightTurnBR[2] = { 35, -35 };


Gaits::Gaits() {}


#define CHECK_CMD(expectedCmd) \
  if (command != (expectedCmd)) { \
    neutralPosition(legs, ssc); \
    return; \
  }


// ------------------------------------------------------
// FORWARD
// ------------------------------------------------------
void Gaits::tripodGaitForward(Leg legs[6], SSC32& ssc) {

  Leg& FL = legs[0];
  Leg& FR = legs[1];
  Leg& ML = legs[2];
  Leg& MR_4 = legs[3];
  Leg& BL = legs[4];
  Leg& BR_6 = legs[5];

  int pulses[18];
  int p[3];

  // CYCLE 1
  for (int i = 0; i <= nbPts; i++) {
    CHECK_CMD('z');

    float zSOL = groundHeight;
    float t = (float)i / nbPts;
    float zAIR = groundHeight + stepHeight * sin(PI * t);

    // SOL : FR, ML, BR
    float xFR = coordinatestripodForwardFR[0] + i * (amplitude / nbPts);
    float xML = coordinatestripodForwardML[0] - i * (amplitude / nbPts);
    float xBR = coordinatestripodForwardBR[0] + i * (amplitude / nbPts);

    inverseKine(xFR, bodyDistanceCorners, zSOL, FR.rotation, FR.alignGroundAngle, p);
    pulses[3] = p[0];
    pulses[4] = p[1];
    pulses[5] = p[2];
    inverseKine(xML, bodyDistance, zSOL, ML.rotation, ML.alignGroundAngle, p);
    pulses[6] = p[0];
    pulses[7] = p[1];
    pulses[8] = p[2];
    inverseKine(xBR, bodyDistanceCorners, zSOL, BR_6.rotation, BR_6.alignGroundAngle, p);
    pulses[15] = p[0];
    pulses[16] = p[1];
    pulses[17] = p[2];

    // AIR : FL, MR, BL
    float xFL = coordinatestripodForwardFL[1] + i * (amplitude / nbPts);
    float xMR = coordinatestripodForwardMR[1] - i * (amplitude / nbPts);
    float xBL = coordinatestripodForwardBL[1] + i * (amplitude / nbPts);

    inverseKine(xFL, bodyDistanceCorners, zAIR, FL.rotation, FL.alignGroundAngle, p);
    pulses[0] = p[0];
    pulses[1] = p[1];
    pulses[2] = p[2];
    inverseKine(xMR, bodyDistance, zAIR, MR_4.rotation, MR_4.alignGroundAngle, p);
    pulses[9] = p[0];
    pulses[10] = p[1];
    pulses[11] = p[2];
    inverseKine(xBL, bodyDistanceCorners, zAIR, BL.rotation, BL.alignGroundAngle, p);
    pulses[12] = p[0];
    pulses[13] = p[1];
    pulses[14] = p[2];

    ssc.sendAllServos(pulses, velocity / nbPts);
  }

  // CYCLE 2
  for (int i = 0; i <= nbPts; i++) {
    CHECK_CMD('z');

    float zSOL = groundHeight;
    float t = (float)i / nbPts;
    float zAIR = groundHeight + stepHeight * sin(PI * t);

    // SOL : FL, MR, BL
    float xFL = coordinatestripodForwardFL[0] - i * (amplitude / nbPts);
    float xMR = coordinatestripodForwardMR[0] + i * (amplitude / nbPts);
    float xBL = coordinatestripodForwardBL[0] - i * (amplitude / nbPts);

    inverseKine(xFL, bodyDistanceCorners, zSOL, FL.rotation, FL.alignGroundAngle, p);
    pulses[0] = p[0];
    pulses[1] = p[1];
    pulses[2] = p[2];
    inverseKine(xMR, bodyDistance, zSOL, MR_4.rotation, MR_4.alignGroundAngle, p);
    pulses[9] = p[0];
    pulses[10] = p[1];
    pulses[11] = p[2];
    inverseKine(xBL, bodyDistanceCorners, zSOL, BL.rotation, BL.alignGroundAngle, p);
    pulses[12] = p[0];
    pulses[13] = p[1];
    pulses[14] = p[2];

    // AIR : FR, ML, BR
    float xFR = coordinatestripodForwardFR[1] - i * (amplitude / nbPts);
    float xML = coordinatestripodForwardML[1] + i * (amplitude / nbPts);
    float xBR = coordinatestripodForwardBR[1] - i * (amplitude / nbPts);

    inverseKine(xFR, bodyDistanceCorners, zAIR, FR.rotation, FR.alignGroundAngle, p);
    pulses[3] = p[0];
    pulses[4] = p[1];
    pulses[5] = p[2];
    inverseKine(xML, bodyDistance, zAIR, ML.rotation, ML.alignGroundAngle, p);
    pulses[6] = p[0];
    pulses[7] = p[1];
    pulses[8] = p[2];
    inverseKine(xBR, bodyDistanceCorners, zAIR, BR_6.rotation, BR_6.alignGroundAngle, p);
    pulses[15] = p[0];
    pulses[16] = p[1];
    pulses[17] = p[2];

    ssc.sendAllServos(pulses, velocity / nbPts);
  }
}
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

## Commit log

2026-06-08 electronic readme
    Added detailed information about the power system and safety features of HexaRescue.
2026-06-08 Update README with Jetson Nano detection details
    Added information about Jetson Nano and YOLOv5 detection.
